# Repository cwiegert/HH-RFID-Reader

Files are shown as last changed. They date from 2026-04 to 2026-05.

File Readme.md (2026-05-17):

# EMU NFC Gate Reader

> NFC spool identification for Happy Hare: use one reader per EMU lane, or one shared reader inside the MMU body.

This project supports two operating models:

- **Per-lane readers:** each EMU gate gets its own PN532 reader. When you load a spool, NFC can scan-jog the filament until the tag rotates into read range, resolve the spool in Spoolman, and update Happy Hare's gate map automatically.
- **Shared reader:** one PN532 is mounted inside the MMU body. Tap the spool tag before loading, then insert filament into any gate. When Happy Hare starts pregate preload, NFC stages that spool ID for the gate being loaded.

Per-lane flow:

```
Load spool → HH parks filament → scan-jog rotates spool → tag in range → Spoolman lookup → Happy Hare gate map
```

Shared-reader flow:

```
Tap tag → spool pending → load any MMU gate → HH pregate preload → spool assigned
```

---

## What You Need

- A Voron with an EMU running ~~[Happy Hare](https://github.com/moggieuk/Happy-Hare)~~
- The [igiannakas IG-dev branch](https://github.com/igiannakas/Happy-Hare/tree/IG-dev) of Happy Hare.
- One mcu per filament lane (EBB36, EBB42, or SLB)
- One PN532 NFC reader module per gate (~$3–5 each)    the holder is designed for [35mm PCB](https://www.amazon.com/dp/B0DDKX2JCD)
- M2 x 4 self-tapping screws to mount each PN532 to the bracket
- Spoolman running and accessible from the Pi
- NFC tags on your spools (NTAG213/215/216 or Mifare Classic)

---

## Documentation

| | Guide | What it covers |
|---|---|---|
| 1 | [Wiring](docs/i2c-pn532/wiring.md) | Pin connections, I2C mode selection, pull-ups |
| 2 | [Install](docs/shared/install-uninstall.md) | Clone, run installer, configure Moonraker updates |
| 3 | [Setup](docs/i2c-pn532/setup.md) | printer.cfg includes, lane config, first boot |
| 4 | [Spoolman Integration](docs/shared/spoolman-integration.md) | Create the extra field, register tag UIDs |
| 5 | [Commands & Macros](docs/shared/klipper-functions.md) | Every GCode command with examples |
| 6 | [Configuration Reference](docs/shared/configuration.md) | All settings with defaults |
| 7 | [Message Definitions](docs/shared/message_definition.md) | Console messages and `nfc_reader.log` entries for per-lane and shared readers |
| 8 | [Troubleshooting](docs/i2c-pn532/troubleshooting.md) | Failure patterns and fixes |
| 9 | [How It Works](docs/shared/how-it-works.md) | Boot sequence, poll flow, system layers, macro events |
| 10 | [Expert: Low-Level I2C Debug](docs/shared/expert-low-level-i2c-debugging.md) | Manual PN532 bus commands |

---

## Scan-and-Jog: How the Tag Gets Read

NFC tags sit on the spool hub. When Happy Hare parks filament at the gate the hub face may not be aligned over the antenna — the tag could be facing any direction. Scan-and-jog solves this automatically.

**Automatic path (normal operation):**
1. Happy Hare finishes loading filament and sets gate_status → 1 (parked)
2. NFC_Manager detects the 0→1 edge on the next poll tick
3. The scan-jog loop starts — filament advances in `scan_jog_mm` steps (default 75 mm), reading the NFC tag after each step
4. The moment the tag rotates into read range, the spool is identified through Spoolman and dispatched to Happy Hare
5. The filament rewinds to the parked position via `MMU_UNLOAD restore=0`

**Manual trigger:** If the automatic trigger didn't fire (or you want to retry), run:
```gcode
NFC GATE=0 JOG_SCAN=1
```
This runs the exact same sequence with the same precondition checks (HH idle, not printing, no other gate scanning).

**Happy Hare post-preload hook (alternative to automatic polling):** The [igiannakas IG-dev branch](https://github.com/igiannakas/Happy-Hare/tree/IG-dev) of Happy Hare adds a `variable_user_post_preload_extension` hook. Configure it to trigger NFC scan-jog automatically after each `MMU_PRELOAD`:

```ini
[gcode_macro _MMU_SEQUENCE_VARS]
variable_user_post_preload_extension: 'NFC JOG_SCAN=1'
```

Happy Hare appends `GATE=<n>` automatically, giving `NFC JOG_SCAN=1 GATE=<n>`. Use this recommended config with the hook:

```ini
startup_polling: 0
scan_enabled:    False
```

This disables gate-status polling entirely — Happy Hare calls NFC only after the relevant gate completes preload. See [Configuration Reference](docs/shared/configuration.md) for full details.

**Tag-not-in-Spoolman behavior:** If the tag UID is detected but not registered in Spoolman, the gate is kept `AVAILABLE=1` with `SPOOLID=-1` so Happy Hare still treats the lane as loaded. The console prompts the user to add the UID to Spoolman.

**Configurable per lane** — see [Configuration Reference](docs/shared/configuration.md):

| Key | Default | Effect |
|---|---|---|
| `scan_enabled` | `False` | Automatic gate-status trigger; keep `False` when using the Happy Hare post-preload hook |
| `scan_jog_mm` | `75.0` | Filament advance per step (mm) |
| `scan_reads_per_position` | `3` | NFC read attempts at each stopped scan position before the next substep |
| `scan_rewind_buffer_mm` | `30.0` | Distance left for Happy Hare's final gate parking step |
| `scan_decode_retry_mm` | `2.0` | Distance between nearby retry positions after an incomplete rich tag read |
| `scan_decode_retry_rounds` | `5` | Nearby retry rounds; each round probes both sides of the first UID hit |
| `scan_poll_interval` | `0.1` | Seconds between stopped-position NFC reads during scan |

During scan-jog, gate `N` also guards against the rare case where its reader
sees the parked spool on gate `N - 1`. If the read UID exactly matches the left
neighbor's cached UID, NFC shifts that neighbor 75 mm out of range, continues
scanning the current gate, and restores the neighbor on scan exit.

---

## Shared Reader

An optional single PN532 mounted inside the MMU body — not tied to any EMU lane. Tap a tagged spool on it before loading; Happy Hare automatically assigns that spool to whichever gate gets the next pregate preload.

```
tap spool on shared reader → blinking LED → spool pending
insert filament into MMU gate → pregate preload → HH assigns spool ID
```

Happy Hare already has the mechanism:

```gcode
MMU_GATE_MAP NEXT_SPOOLID=<spool_id>
```

The shared reader issues this command at `variable_user_pre_load_extension` time — just before preload starts. Happy Hare assigns it to the loaded gate; NFC clears the pending state.

**Setup:** include `nfc_reader_shared.cfg` and wire the Happy Hare pre-load hook to `_NFC_SHARED_PRELOAD`. See [Shared Reader](docs/shared/shared-reader.md) for the full workflow, [Configuration Reference](docs/shared/configuration.md#shared-reader) for the config block, and [Commands & Macros](docs/shared/klipper-functions.md#shared-reader) for operation.

---

## Quick Install

> [!IMPORTANT]
> Before installing, rebuild and flash Klipper firmware on every EBB42 / lane MCU. The NFC driver talks to the MCU directly over I2C — if MCU firmware is stale, failures look like hardware problems. See [the full warning below](#mcu-firmware-warning).

SSH to the Pi and clone the repo:

```bash
cd ~
git clone https://github.com/cwiegert/HH-RFID-Reader.git emu-nfc-reader
cd ~/emu-nfc-reader
bash install.sh
```

Add the matching includes to `printer.cfg` — **order matters**.

Per-lane readers:

```ini
[include nfc/nfc_reader.cfg]
[include nfc/nfc_macros.cfg]
[include nfc/nfc_reader_hw.cfg]
```

Shared-reader-only:

```ini
[include nfc/nfc_reader.cfg]
[include nfc/nfc_macros.cfg]
[include nfc/nfc_reader_shared.cfg]
```

Hybrid install with per-lane readers and a shared reader:

```ini
[include nfc/nfc_reader.cfg]
[include nfc/nfc_macros.cfg]
[include nfc/nfc_reader_hw.cfg]
[include nfc/nfc_reader_shared.cfg]
```

Set your Spoolman URL in `~/printer_data/config/nfc/nfc_reader.cfg`:

```ini
[nfc_gate]
spoolman_url:      auto
spoolman_rfid_key: rfid_tag
```

Add the Moonraker update block to `moonraker.conf`:

```ini
[update_manager emu_nfc_reader]
type:             git_repo
path:             ~/emu-nfc-reader
origin:           https://github.com/cwiegert/HH-RFID-Reader.git
primary_branch:   main
managed_services: klipper
install_script:   install.sh
info_tags:        desc=EMU NFC Gate Reader for Happy Hare
```

Restart and verify:

```bash
sudo systemctl restart klipper moonraker
```

```gcode
NFC_STATUS
```

Expected (with no tags loaded):
```
NFC gate status  (4 gates configured):
  Gate 0  [lane0]:  empty
  Gate 1  [lane1]:  empty
  Gate 2  [lane2]:  empty
  Gate 3  [lane3]:  empty
```

See [Install & Uninstall](docs/shared/install-uninstall.md) for the complete first-boot checklist.

---

## Day-to-Day Commands

These are the commands you'll actually use at the Fluidd/Mainsail console:

```gcode
NFC_HELP                      ; show everyday command help
NFC_HELP ADVANCED=1 CALLBACKS=1 LOW_LEVEL=1  ; show the full command set
NFC_STATUS                    ; see all gates at a glance
NFC GATE=0 SCAN=1             ; read a tag and show its UID
NFC GATE=0 POLL=1             ; full cycle: read → Spoolman → Happy Hare
NFC GATE=0 JOG_SCAN=1         ; start scan-jog (same as automatic pre-load trigger)
NFC GATE=0 READ=1             ; start automatic background polling
NFC GATE=0 READ=0             ; stop polling
```

See [Commands & Macros](docs/shared/klipper-functions.md) for everything, including how to test the Happy Hare handoff without hardware.

---

See [How It Works](docs/shared/how-it-works.md) for the boot sequence, per-poll flow, system layers, and macro dispatch events.

---

> [!CAUTION]
> ## 🔴⚡ Your Lane MCUs Should Run Firmware Built From Your Current Host firmware version
>
> This is the number one cause of mysterious NFC failures — and it looks nothing like a firmware problem. It looks like broken wiring, a dead PN532, a misconfigured I2C bus, or a ghost in the machine.
>
> **Here's what's actually happening:** The PN532 driver doesn't talk to Klipper software on the Pi. It talks directly to the firmware running on each EBB42 over I2C. When you run `git pull` on the Pi, the host updates — but every lane MCU is still running whatever firmware it had before. Now they speak different protocol versions, and I2C transactions start silently failing:
>
> - 🔇 ACK reads fail immediately after the ready byte succeeds
> - ⏱️ `i2c_read_response` timeouts appear out of nowhere
> - 🌡️ Your BME280 on the same bus starts misbehaving for no apparent reason
>
> **The fix is not in the wiring. It is not in the config. It is in the firmware.**
>
> Every time you update Klipper — before you touch NFC config, before you run `INIT`, before you blame the hardware — do this:
>
> ```
> 1. git pull                          ← update the Klipper host checkout
> 2. Build MCU firmware                ← compiled from THAT exact host version
> 3. Flash every lane MCU / EBB42      ← every one, not just lane0
> 4. sudo systemctl restart klipper
> 5. Confirm all lane MCUs reconnect   ← check Fluidd/Mainsail before testing NFC
> ```
>
> ✅ Host and MCU firmware versions match → NFC works reliably
> ❌ Host updated, MCUs not reflashed → NFC fails in ways that will waste hours

---

## License

Copyright (C) 2026 WoodWorker.
Licensed under [GNU General Public License v3.0 or later](https://www.gnu.org/licenses/gpl-3.0.html).
See [LICENSE](LICENSE) for the full terms.

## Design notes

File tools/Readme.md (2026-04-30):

# pn532_scan.py — Standalone PN532 Scanner

Reads a PN532 NFC reader directly from a Raspberry Pi using the native Linux
I2C layer — no Klipper, no MCU, no CAN bus required.

Use this to confirm wiring and tag detection before integrating with Klipper.

---

## Prerequisites

### Enable I2C on the Pi

```bash
sudo raspi-config
```

Navigate to **Interface Options → I2C → Enable**, then reboot.

Confirm the device is present:

```bash
ls /dev/i2c-*
# expected: /dev/i2c-1
```

### Install smbus2

```bash
sudo apt install python3-smbus2
```

---

## Wiring

| PN532 Pin | Pi Pin | Pi GPIO |
|---|---|---|
| VCC | Pin 1 | 3.3V |
| GND | Pin 6 | GND |
| SDA | Pin 3 | GPIO2 (I2C1 SDA) |
| SCL | Pin 5 | GPIO3 (I2C1 SCL) |

> **I2C mode:** Set the PN532 to I2C mode before wiring (DIP switch or solder jumper).
>
> | SEL0 | SEL1 | Mode |
> |---|---|---|
> | L | L | SPI |
> | **H** | **L** | **I2C ← use this** |
> | L | H | HSU (UART) |

> **Default address:** `0x24` — change with `--address` if your ADDR pins are set differently.

---

## Usage

Run from the repository root on the Pi.

### Step 1 — Confirm the PN532 is visible on the bus

```bash
python3 tools/pn532_scan.py --scan-bus
```

Expected output:

```
Scanning I2C bus 1 for devices...
  0x24  (36)

1 device(s) found.
```

If nothing appears — check wiring and the I2C mode jumper.

---

### Step 2 — Poll for tags

```bash
python3 tools/pn532_scan.py
```

```
PN532 scanner — I2C bus 1, address 0x24
Poll interval: 2.0s   Debug: 1
Press Ctrl+C to stop.

Initialising PN532...
PN532 ready.

TAG DETECTED  UID=A3F200CC
Tag removed.
```

Press **Ctrl+C** to stop.

---

### Options

| Option | Default | Description |
|---|---|---|
| `--bus N` | `1` | I2C bus number (`/dev/i2c-N`) |
| `--address 0xNN` | `0x24` | PN532 I2C address |
| `--poll N` | `2.0` | Poll interval in seconds |
| `--debug` | off | Full protocol trace (every I2C transaction) |
| `--once` | off | Exit after first tag read |
| `--scan-bus` | off | Scan bus for all responding devices and exit |

---

### Full protocol trace

```bash
python3 tools/pn532_scan.py --debug
```

Prints every I2C transaction — useful when the PN532 initialises but tags are not detected.

---

### Read one tag and exit

```bash
python3 tools/pn532_scan.py --once
```

---

## Troubleshooting

**"smbus2 is not installed"**
```bash
sudo apt install python3-smbus2
```

**"ERROR: PN532 gate 0 did not respond"**
1. Run `--scan-bus` — if `0x24` is not listed the chip is not on the bus
2. Confirm the PN532 is in **I2C mode** — most common cause of no response
3. Check VCC is **3.3V** (not 5V), SDA → Pin 3, SCL → Pin 5
4. Confirm I2C is enabled: `sudo raspi-config → Interface Options → I2C`

**"Permission denied: /dev/i2c-1"**
```bash
sudo usermod -aG i2c $USER
# log out and back in, then retry
```

**Tag not detected**
- Hold tag flat and close (< 3 cm) to the antenna coil
- Run `--debug` to see whether `InListPassiveTarget` is completing
- Try rotating the tag — some tags are orientation-sensitive

---

*Copyright (C) 2026 WoodWorker. Licensed under [GPL-3.0-or-later](https://www.gnu.org/licenses/gpl-3.0.html) — see [LICENSE](../LICENSE).*

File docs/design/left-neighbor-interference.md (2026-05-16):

# Design: Left-Neighbor Tag Interference During Scan-Jog

> Engineering reference. Not end-user documentation.
> Status: **Implemented** — `scan_jog.py` mitigation, `nfc_manager.py`
> lane lookup support, and scan-jog tests.

## Problem

Some tagged spools expose NFC/RFID tags on both sides of the spool. In an EMU
layout where each PN532 reader is mounted on the left side of its own spool, the
reader for gate `N` can occasionally see the tag on gate `N - 1` instead of the
spool currently being scan-jogged.

This is most likely during scan-jog:

- gate `N` is rotating to find its own tag
- gate `N - 1` is already loaded and parked
- one side tag on gate `N - 1` is sitting in gate `N` reader's field

The current NFC state machine assumes the UID returned by a gate reader belongs
to that gate. That assumption is still correct for normal operation, but it can
misassign a spool during this physical edge case.

## Scope

Recommended scope is intentionally narrow:

- only inspect the immediate left neighbor, `gate - 1`
- do nothing for gate `0`
- only apply mitigation while scan-jog is active
- only apply mitigation while Happy Hare is idle and lanes passed the existing
  parked-or-empty preflight
- do not add a configuration option
- always restore the left neighbor if it was moved
- do not add global cross-gate UID matching

This keeps the behavior matched to the physical mounting geometry instead of
turning the NFC manager into a global spool reconciliation system.

## Existing Safety Boundaries

The current implementation already provides useful protection:

- only one scan-jog may run at a time via `NFCGate._active_scan_gate`
- scan-jog is blocked unless Happy Hare reports all lanes parked or empty
- each gate owns its own reader
- scan-jog suppresses dispatch until after the rewind path
- incomplete structured reads can be retried nearby

The missing piece is identity disambiguation after a UID is read but before the
scan is accepted as successful.

## Insertion Point

The implementation lives in:

`klippy/extras/nfc_gates/scan_jog.py`

The best insertion point is inside `step_event()`, immediately after:

```python
tag_found = gate._poll()
```

and before the existing `if tag_found:` success path.

At this point:

- the PN532 read has happened
- `tag_handler.resolve_spool()` has already resolved UID to spool where possible
- `GateState.process_read()` has updated `gate._state`
- scan-jog dispatch is still deferred in `gate._scan_found_event`
- no Happy Hare assignment has been sent yet

That makes it possible to reject the read, clear the deferred event, move the
left neighbor out of the RF field, and continue scanning gate `N`.

Implemented call shape:

```python
tag_found = gate._poll()

if tag_found and handle_left_neighbor_interference(gate, now):
    return gate.reactor.monotonic() + gate._scan_poll_interval
```

## Detection Strategy

### Spoolman-enabled path

If Spoolman is enabled, the first identity test should still be UID-to-UID, not
UID-to-spool. The raw UID is the direct physical identity returned by the PN532.
If gate `N` reads the same UID already known for gate `N - 1`, the tag belongs
to the left neighbor and there is no reason to resolve the read UID to a
Spoolman spool before acting.

Implemented order:

1. Confirm gate `N` parsed a `spool_identity`.
2. Find the known `spool_identity` for gate `N - 1` from the left NFC gate
   object's `current_tag`.
3. If the left gate has a known `spool_identity` and it matches the current
   identity, treat the read as interference immediately.
4. Discard the read, jog gate `N - 1` out of the reader field, and continue
   scan-jog for gate `N`.
5. If either identity is unavailable or they do not match, fall out to the
   default scan-jog behavior.

This avoids unnecessary Spoolman resolution for the strong-match case. The
identity comparison answers "did this reader see the same factory spool as the
left gate?" without relying on physical tag UIDs.

Helper logic:

```python
def read_uid_from_scan_event(gate):
    event = getattr(gate, '_scan_found_event', None)
    if event is not None and len(event) >= 3:
        return event[2]
    return gate._state.current_uid
```

Then:

```python
left_gate = gate._gate - 1
if left_gate < 0:
    return False

current_identity = current_spool_identity(gate)
if current_identity is None:
    return False

left_identity = spool_identity_for_gate(gate, left_gate)
if left_identity is not None and left_identity == current_identity:
    return True
```

The `spool_identity_for_gate()` helper is cheap and conservative. Preferred source:

1. The left `NFCGate.current_tag.spool_identity`, if present.

Happy Hare may be used as a safety check that the left gate is still physically
loaded or available, but it should not be used to resolve identity. Likewise,
the implementation must not fall back from `spool_identity` to `uid`,
`spool_id`, material, color, or display metadata. If either side has no
`spool_identity`, there is no positive interference proof.

If no left `spool_identity` can be established, or if the known left identity
does not match the current identity, the mitigation should return `False` and
let normal scan-jog continue. The resolved `spool_id` is useful for the normal
assignment flow, but it is not the decision point for left-neighbor
interference.

### Spoolman-disabled path

When Spoolman is disabled, the same `spool_identity` rule still applies. Do not
invent a Happy Hare metadata convention just to smuggle identity through display
names. The NFC layer already owns per-gate state, and `NFC_STATUS` shows each
gate's cached `spool_identity` when parser metadata supplies one.

Recommended order:

1. Confirm gate `N` has `current_tag.spool_identity`.
2. Resolve the left NFC gate object for `N - 1`.
3. Read `left_gate._state.current_tag.spool_identity`.
4. If the left NFC gate has a cached `spool_identity` and it matches the
   current identity, treat the read as interference immediately.
5. If either side has no `spool_identity`, or the identities do not match,
   return `False` and let normal scan-jog continue.

This keeps the no-Spoolman path a corner case with the same core rule:

```python
left_nfc = nfc_gate_for_gate_number(gate._gate - 1)
if left_nfc is None:
    return False

left_identity = left_nfc._state.current_tag.spool_identity
return left_identity is not None and left_identity == current_identity
```

Happy Hare can still be used as a sanity check that the left lane is physically
loaded or available, but HH does not need to carry the identity. Identity
comparison comes from NFC parser metadata, not from gate names or display
metadata.

## Mitigation Strategy

If the current scan reads the left neighbor:

1. Log the decision, including current gate, left gate, UID, and spool ID when
   available.
2. Select the left gate.
3. Jog the left gate in the positive `MMU_TEST_MOVE` direction by a fixed
   distance. This is the "push filament out" direction for the parked left
   neighbor.
4. Wait for the move to complete.
5. Re-select the current scan gate.
6. Clear the false scan result.
7. Continue the scan-jog loop.

Up to three clearance moves may be attempted per scan. After each move, the
false scan result is cleared and the current lane reads again before any normal
current-lane jog is queued. If the same scan still reads the left neighbor
after the third clearance move, treat that as a larger mechanical/RF fault.
Log and console an `[ERROR]`, abort scan-jog for the current gate, restore the
left neighbor by the accumulated clearance distance, and rewind the current
gate through the normal scan exit path.

Fixed distance:

```python
LEFT_NEIGHBOR_CLEARANCE_MM = 75.0
```

No config option is recommended. A fixed value keeps the feature simple and
avoids adding a tuning knob for a rare hardware geometry problem.

Clearance GCode sequence:

```gcode
MMU_SELECT GATE=<left>
MMU_TEST_MOVE MOVE=75.00 QUIET=1
M400
MMU_SELECT GATE=<current>
```

After shifting the neighbor, clear the false read:

```python
gate._scan_found_event = None
gate._state.current_uid = None
gate._state.current_spool = None
gate._state.miss_count = 0
```

If a structured tag object is present, clear it as well:

```python
gate._state.current_tag = None
```

## Restore Strategy

If the left neighbor was moved, it must be restored from every scan exit path:

- successful scan
- no tag found
- max distance reached
- print-start abort
- scan poll exception path that exits scan-jog

State on `NFCGate`:

```python
gate._scan_left_neighbor_gate = -1
gate._scan_left_neighbor_shift_mm = 0.0
gate._scan_left_neighbor_shifted = False
gate._scan_left_neighbor_identity = None
gate._scan_left_neighbor_attempts = 0
```

Initialize these in `scan_jog.start()`.

Restore helper:

```python
def restore_left_neighbor(gate):
    if not getattr(gate, '_scan_left_neighbor_shifted', False):
        return
    left = gate._scan_left_neighbor_gate
    mm = gate._scan_left_neighbor_shift_mm
    gate._scan_left_neighbor_shifted = False
    gate._scan_left_neighbor_gate = -1
    gate._scan_left_neighbor_shift_mm = 0.0
    gate._scan_left_neighbor_identity = None

    gcode = gate.printer.lookup_object('gcode')
    gcode.run_script(
        "MMU_SELECT GATE=%d\n"
        "MMU_TEST_MOVE MOVE=%.2f QUIET=1\n"
        "M400\n"
        "MMU_SELECT GATE=%d" % (left, -mm, gate._gate))
```

Call this from both `finish()` and `rewind_and_exit()`. The restore should run
after the current gate's rewind is queued, and before the scan state is fully
cleared. The final `MMU_SELECT GATE=<current>` leaves Happy Hare selected on the
gate whose scan just completed.

## State Reset and Scan Continuation

Handling interference should not count as a successful scan. It should behave
like "that UID was not ours; try again after moving the neighbor".

Recommended behavior after the left gate jog:

- keep `gate._scan_mode = True`
- keep `NFCGate._active_scan_gate` held by the current gate
- keep `gate._scan_mm_total` unchanged
- clear current NFC state and deferred event
- set `gate._scan_next_chunk_time` to a short future time so the field can
  settle before polling again

Example:

```python
gate._scan_next_chunk_time = (
    gate.reactor.monotonic() + DECODE_RETRY_SETTLE_DELAY)
```

Using the existing decode retry settle constant is acceptable. A separate
constant can be introduced if hardware testing shows the neighbor shift needs a
different dwell.

## Implementation Notes

This section describes the implemented first pass.

### Identity Rule

Use exactly one positive interference rule:

```text
gate N current_tag.spool_identity = X
left NFC gate current_tag.spool_identity = Y
X exists and Y exists and X == Y -> left-neighbor interference
X missing or Y missing          -> normal scan-jog behavior
X != Y                          -> normal scan-jog behavior
```

This is deliberately conservative for dual-tag factory spools where the two
physical tags have different UIDs. Bambu spools are one observed case: both side
tags can parse to the same `spool_identity` (`bambu_<tray_uid>`) while exposing
different physical NFC UIDs.

Do not use physical tag UID as a fallback for this decision. Do not resolve the
read UID to a Spoolman spool ID for interference detection. Do not compare the
read spool ID to Happy Hare's left-gate spool ID. Do not inspect Happy Hare
display names, material, color, or other metadata for identity information.

### Data Sources

The current identity comes from the current gate's parsed tag state:

1. `gate._state.current_tag.spool_identity`

The left identity comes from the left NFC gate object only:

```python
left_nfc = nfc_gate_for_gate_number(gate._gate - 1)
left_identity = (
    left_nfc._state.current_tag.spool_identity
    if left_nfc is not None and left_nfc._state.current_tag is not None
    else None)
```

Happy Hare may be consulted only to reject stale left-cache data:

```python
left_hh = hh_status.read(gate.printer, gate._gate - 1)
if left_hh.present and not left_hh.available:
    return None
```

If Happy Hare is unavailable, the implementation may still use the left NFC
cache because scan-jog already passed its preflight before starting. The
important part is that HH is not used to translate the current read into an
identity.

### Helper Contracts

Add a lookup helper near the existing `_lane_instances` registry in
`nfc_manager.py`:

```python
def nfc_gate_for_gate_number(gate_number):
    for candidate in _lane_instances:
        if candidate._gate == gate_number:
            return candidate
    return None
```

Expose it to `scan_jog.py` through an `NFCGate` wrapper to avoid importing
`nfc_manager.py` from `scan_jog.py`:

```python
def _nfc_gate_for_gate_number(self, gate_number):
    return nfc_gate_for_gate_number(gate_number)
```

Then `scan_jog.py` can call:

```python
left_nfc = gate._nfc_gate_for_gate_number(gate._gate - 1)
```

### Scan Loop Placement

In `scan_jog.step_event()`, call the interference handler immediately after
`gate._poll()` and before decode retry or finish handling:

```python
tag_found = gate._poll()

if tag_found and handle_left_neighbor_interference(gate, now):
    return gate.reactor.monotonic() + gate._scan_poll_interval
```

This placement matters. `_poll()` has already captured the UID and deferred the
event, but scan-jog has not accepted the read, started decode retry, dispatched
to Happy Hare, or finished.

### Interference Handler

The handler should:

1. Read the current scan UID for logging and the current `spool_identity` for
   identity matching.
2. Return `False` for gate `0`.
3. Return `False` if the current `spool_identity` is empty.
4. Read the left NFC gate object and its cached `spool_identity`.
5. Return `False` if the left identity is empty or does not match.
6. If the left neighbor was already shifted during this scan and the same left
   gate/identity is still being read, log a fault, abort scan-jog, and return `True`.
7. Log the interference decision.
8. Move the left gate out of range. If the shift command fails, log the
   failure, clear no scan state, return `False`, and let normal scan-jog
   behavior continue.
9. Clear the current gate's false read state.
10. Keep scan-jog active and return `True`.

The handler should not inspect or compare spool IDs.

### Left-Gate Movement

Use a single fixed displacement:

```python
LEFT_NEIGHBOR_CLEARANCE_MM = 75.0
```

The shift GCode should explicitly select the left gate, move it in the positive
`MMU_TEST_MOVE` direction to push filament out, wait, then select the current
gate:

```gcode
MMU_SELECT GATE=<left>
MMU_TEST_MOVE MOVE=75.00 QUIET=1
M400
MMU_SELECT GATE=<current>
```

Set restore state only after the shift command is successfully queued:

```python
gate._scan_left_neighbor_gate = left
gate._scan_left_neighbor_shift_mm = 75.0
gate._scan_left_neighbor_shifted = True
gate._scan_left_neighbor_identity = spool_identity
```

If the shift command raises, log a warning, clear no state, and return `False`
so normal scan-jog behavior continues.

Retry clearance moves conservatively. If `gate._scan_left_neighbor_shifted` is
already `True` for the same left gate and `spool_identity`, the implementation
may call `MMU_TEST_MOVE MOVE=75.00` again until three total clearance moves
have been queued. Each retry clears the false scan result and reads again
before normal current-lane scan-jog movement resumes.

If the same `spool_identity` is still visible after the third clearance move
and follow-up read, report an error and exit scan-jog:

```text
[ERROR] NFC[<current>]: left lane gate <left> is interfering with the current lane read after 3 clearance moves (<mm>mm); check reader position, tag placement, or lane spacing
```

That exit should use the normal rewind/restore path so the neighbor is returned
with `MMU_TEST_MOVE MOVE=-<total clearance>` and the current gate is rewound.

### False Read Cleanup

After a confirmed left-neighbor `spool_identity` match and successful left-gate
shift, clear:

```python
gate._scan_found_event = None
gate._state.current_uid = None
gate._state.current_spool = None
gate._state.current_tag = None
gate._state.miss_count = 0
```

Also clear decode-retry state if it had been initialized from the false UID:

```python
gate._scan_decode_retry_attempts = 0
gate._scan_decode_retry_uid = None
gate._scan_decode_retry_offset = 0.0
```

Do not change `gate._scan_mm_total`; the current gate has not moved.

### Restore Ordering

Call `restore_left_neighbor(gate)` from both scan exit paths:

- `finish(gate)`
- `rewind_and_exit(gate)`

The restore should run after the current gate's rewind is queued and before the
scan state is fully discarded. This preserves the current gate's normal rewind
behavior and still guarantees the neighbor is put back.

Restore GCode:

```gcode
MMU_SELECT GATE=<left>
MMU_TEST_MOVE MOVE=-75.00 QUIET=1
M400
MMU_SELECT GATE=<current>
```

Clear restore state before running the restore GCode so a restore failure cannot
cause repeated negative moves on later cleanup attempts. Log failures.

## Module Changes

### `scan_jog.py`

Owns:

- interference detection wrapper
- left-neighbor jog GCode
- restore-on-exit state
- clearing false scan results

Recommended additions:

- `LEFT_NEIGHBOR_CLEARANCE_MM`
- `handle_left_neighbor_interference(gate, now)`
- `is_left_neighbor_spool_identity_match(gate)`
- `spool_identity_for_gate(gate, target_gate)`
- `shift_left_neighbor(gate)`
- `restore_left_neighbor(gate)`
- `clear_false_scan_result(gate)`

### `nfc_manager.py`

Keep changes minimal.

Add scan state fields in `NFCGate.__init__` so tests and status are explicit:

```python
self._scan_left_neighbor_gate = -1
self._scan_left_neighbor_shift_mm = 0.0
self._scan_left_neighbor_shifted = False
self._scan_left_neighbor_identity = None
```

Expose or reuse a small lookup helper for the existing NFC gate registry:

```python
def nfc_gate_for_gate_number(gate_number):
    for candidate in _lane_instances:
        if candidate._gate == gate_number:
            return candidate
    return None
```

This helper lets scan-jog read the left gate's cached `current_tag` directly
from the NFC gate object. Parser-supplied `spool_identity` is the source for
this mitigation; Happy Hare does not need an identity field.

No Happy Hare movement commands should be added here. Movement remains in
`scan_jog.py`.

### `hh_status.py`

No display-name or metadata changes are required for this design.

`hh_status.py` may still be used to verify the left lane is physically loaded or
available before trusting a cached `spool_identity`, but it should not be
extended to carry identity through Happy Hare gate metadata.

### `klipper_interface.py`

No changes are required.

Do not append identity suffixes to metadata names for this mitigation. Display
names should remain display names; spool identity stays in NFC parser metadata.

## Pseudocode

```python
def handle_left_neighbor_interference(gate, now):
    if not gate._scan_mode:
        return False
    if gate._gate <= 0:
        return False

    identity = current_spool_identity(gate)
    if identity is None:
        return False

    if not is_left_neighbor_spool_identity_match(gate):
        return False

    left_gate = gate._gate - 1
    if left_neighbor_already_shifted(gate, left_gate, identity) and attempts >= 3:
        msg = (
            "[ERROR] NFC[%d]: left lane gate %d is interfering with the "
            "current lane read after %d clearance moves"
            % (gate._gate, left_gate, attempts))
        logger.error("%s", msg)
        gate._console(msg)
        clear_false_scan_result(gate)
        gate._rewind_and_exit_scan()
        return True

    logger.warning(
        "nfc_gate: [%s] gate %d scan mode - spool_identity=%s belongs "
        "to left neighbor gate %d; moving neighbor out of reader field",
        gate._name, gate._gate, identity, left_gate)

    if not shift_left_neighbor(gate):
        return False
    clear_false_scan_result(gate)
    gate._scan_next_chunk_time = (
        gate.reactor.monotonic() + DECODE_RETRY_SETTLE_DELAY)
    return True

def left_neighbor_already_shifted(gate, left_gate, identity):
    return (
        gate._scan_left_neighbor_shifted
        and gate._scan_left_neighbor_gate == left_gate
        and gate._scan_left_neighbor_identity == identity)

def current_spool_identity(gate):
    tag = gate._state.current_tag
    return getattr(tag, 'spool_identity', None) if tag is not None else None

def is_left_neighbor_spool_identity_match(gate):
    if gate._gate <= 0:
        return False
    identity = current_spool_identity(gate)
    if identity is None:
        return False

    left_gate = gate._gate - 1
    left_identity = spool_identity_for_gate(gate, left_gate)
    if left_identity is None:
        return False

    return left_identity == identity

def spool_identity_for_gate(gate, target_gate):
    left_nfc = gate._nfc_gate_for_gate_number(target_gate)
    left_tag = left_nfc._state.current_tag if left_nfc is not None else None
    left_identity = (
        getattr(left_tag, 'spool_identity', None)
        if left_tag is not None else None)
    if left_identity is None:
        return None

    # Optional stale-cache guard. HH is not used to resolve identity; it can
    # only veto cached left metadata when it clearly says the left gate is empty.
    left = hh_status.read(gate.printer, target_gate)
    if left.present and not left.available:
        return None

    return left_identity
```

## Tests

Add tests to:

`tests/test_scan_jog_mode.py`

Recommended cases:

- gate `0` never checks a left neighbor
- read matching the known left `spool_identity` shifts left and does not finish
  scan
- read with a different left `spool_identity` finishes normally
- read with no known left `spool_identity` falls through to normal scan-jog
  behavior
- left gate assigned but not available does not trigger mitigation
- after interference, false `_scan_found_event` and `GateState` values are
  cleared
- `finish()` restores the left gate if shifted
- `rewind_and_exit()` restores the left gate if shifted
- repeated left-neighbor hits after the first clearance do not issue another
  `MOVE=75.00`; they warn, abort scan-jog, restore the neighbor, and rewind the
  current gate
- Spoolman-disabled reads use the same parser-supplied `spool_identity` rule

The tests should assert emitted GCode order, especially:

```text
MMU_SELECT GATE=<left>
MMU_TEST_MOVE MOVE=75.00 QUIET=1
M400
MMU_SELECT GATE=<current>
```

and restore:

```text
MMU_SELECT GATE=<left>
MMU_TEST_MOVE MOVE=-75.00 QUIET=1
M400
MMU_SELECT GATE=<current>
```

## Risks and Notes

- The no-Spoolman path depends on parser metadata having supplied
  `spool_identity` for both the current and left NFC gate objects. If either is
  missing, the mitigation should degrade gracefully by returning `False` and
  letting normal scan-jog continue.
- Moving the left neighbor assumes all lanes are parked or empty. The existing
  scan-jog preflight is therefore part of this feature's safety case.
- If the reader still sees the same left-neighbor `spool_identity` after a 75mm
  clearance move, the problem is likely mechanical placement, reader field
  overlap, tag placement, or lane spacing. The implementation should surface
  that condition clearly and stop the scan instead of pushing the neighbor
  farther out.
- The mitigation should be conservative about what counts as interference.
  False positives move a neighboring parked spool unnecessarily. False
  negatives preserve current behavior.
- The feature should log clearly but avoid console spam. A single warning per
  interference event is enough.

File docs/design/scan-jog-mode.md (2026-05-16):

# Design: Scan-and-Jog Mode (Spool Pre-load NFC Identification)

> Engineering reference — not end-user documentation.
> Status: **Implemented** — `scan_jog.py` module, integrated into `nfc_manager.py`
> Source: `klippy/extras/nfc_gates/scan_jog.py`, `klippy/extras/nfc_gates/nfc_manager.py`

---

## Problem Statement

When a spool is manually loaded into a lane, Happy Hare parks the filament at the gate entrance (gate_status → 1, action → Idle). At that point the NFC tag is on the spool hub — potentially centimeters away from the PN532 antenna. The normal polling loop may not read the tag at all if the hub face isn't already aligned over the reader. The user needs a mode where, after filament is parked at the gate, the system automatically spins the spool in small increments to find the tag, identifies the spool, and then winds back to the parked position.

---

## Constraints

- Must not run during an active print.
- Must not run while HH is executing any MMU operation (Loading, Unloading, Homing, etc.).
- Must not require a GCode macro to drive the loop — the control logic must stay in Python.
- Must rewind to the original parked position.
- Rewind must fire even if the search is aborted (max distance reached, print starts mid-scan).
- Must not use `UPDATE_DELAYED_GCODE` — timer lifecycle is owned entirely by the Klipper reactor.

---

## Why Not a GCode Macro Loop

Driving the jog loop from GCode would require a `[delayed_gcode]` that reschedules itself, a cancel mechanism (no clean cancel exists), and scope crossing on every iteration. The Python-only approach eliminates all three problems. Reactor timers are first-class objects: they start, reschedule, and cancel entirely within `_scan_step_event` return values. The jog command (`MMU_TEST_MOVE`) is still issued via `gcode.run_script()`, which is safe from the reactor thread — the same pattern used by `KlipperInterface._run_gcode()`.

---

## Code Structure

All scan-jog logic lives in `klippy/extras/nfc_gates/scan_jog.py` as module-level functions. `NFCGate` in `nfc_manager.py` delegates to them via thin wrapper methods:

```python
# NFCGate wrappers in nfc_manager.py
def _start_scan_mode(self):   return scan_jog.start(self)
def _scan_step_event(self, t): return scan_jog.step_event(self, t)
def _finish_scan(self):        return scan_jog.finish(self)
def _rewind_and_exit_scan(self): return scan_jog.rewind_and_exit(self)
def _run_jog(self, mm):        return scan_jog.run_jog(self, mm)
def _run_rewind(self):         return scan_jog.run_rewind(self)
```

`gate` is passed as the first argument to every `scan_jog` function so it can read and write `gate._scan_mode`, `gate._scan_mm_total`, etc. directly.

---

## Trigger Detection

Trigger detection is folded into `_poll_timer_event`. The gate-status edge-detection path runs every tick when `scan_enabled` is True:

```
_poll_timer_event (every poll_interval)
  ├── read HH gate_status (Python dict — no I2C)
  │
  ├── curr == 0  → skip I2C entirely; also handles _hh_load_paused resume/suspend
  │
  ├── 0→1 edge  → set _scan_pending = True; reset _scan_idle_ready_time
  │
  ├── _scan_pending == True AND curr == 1 AND hh.idle AND not printing
  │     first fire:  _scan_idle_ready_time = now + 2.0  → return that time
  │     settled:     _scan_pending = False
  │                  if NFCGate._active_scan_gate is not None:
  │                      re-arm _scan_pending, retry in 3.0 s
  │                  else:
  │                      _start_scan_mode() → park poll timer, return NEVER
  │
  └── _scan_pending == True but conditions not met → return now + 1.0
```

**Key details:**
- `_prev_gate_status` initializes to `-1` on startup. The `-1 → 1` transition at cold start is ignored; only `0 → 1` triggers scan mode. This prevents a false trigger when HH already has `gate_status = 1` from a previous session.
- A 2-second idle-settle delay (`_scan_idle_ready_time`) is inserted after HH reports idle. This prevents premature scan entry while HH is still completing its park move.
- If another gate holds the scan lock, `_scan_pending` is re-armed and a 3-second retry is scheduled rather than silently dropping the trigger or spamming logs.

**Manual trigger:** `NFC GATE=N JOG_SCAN=1` calls `scan_jog.manual_jog_scan(gate, gcmd)` directly. It runs the same precondition checks (not printing, HH idle, no other gate scanning, reader healthy) and calls `start(gate)`. No edge detection is involved. Happy Hare prep is always required, but `_NFC_GATE_CLEAR_CACHE GATE=N` and `MMU_SPOOLMAN SYNC=1` are deferred to the scan timer so a Happy Hare post-preload hook can return before NFC calls back into HH.

---

## Gate Context and Scan Lock

If two lanes entered scan mode concurrently, their `MMU_SELECT GATE=N` calls would interleave and `MMU_TEST_MOVE` would move the wrong lane's filament. Because all `nfc_gate` instances run on the same reactor thread, a **class-level lock** is sufficient:

```python
# Class variable — shared across all NFCGate instances
NFCGate._active_scan_gate = None   # gate number that currently holds the lock, or None
```

Rules:
- **Entry**: `scan_jog.start()` sets `NFCGate._active_scan_gate = gate._gate`.
- **Hold**: while scan is running, `_active_scan_gate` is non-None. Other gates re-arm `_scan_pending` and retry in 3 seconds.
- **Release**: both `finish()` and `rewind_and_exit()` set `NFCGate._active_scan_gate = None`.
- `_handle_disconnect` also clears the lock if this gate owns it.

Normal polling (I2C reads, no MMU moves) is not gated by this lock.

---

## State Machine

```
              klippy:
              connect ──► POLLING ──(0→1, HH idle, not printing)──► SCAN_JOG
                           ▲                                               │
                           │        tag found OR max_mm OR print starts   │
                           └───────────────────────────────────────────────┘
```

When scan mode starts, the poll timer is parked at `NEVER` and `_scan_timer` takes over. When scan mode ends, `_scan_timer` returns `NEVER` and the poll timer is resumed.

---

## Instance State Variables

```python
# Class variable — shared across all NFCGate instances
NFCGate._active_scan_gate = None   # gate number holding the scan lock, or None

# Timers
self._scan_timer           = None      # registered only during active scan

# Scan mode
self._scan_mode            = False
self._scan_mm_total        = 0.0       # mm jogged forward so far
self._scan_next_chunk_time = 0.0       # reactor timestamp when next jog chunk may fire
self._scan_found_event     = None      # cached event suppressed during jog; dispatched after rewind

# Left-neighbor interference mitigation
self._scan_left_neighbor_gate = -1
self._scan_left_neighbor_shift_mm = 0.0
self._scan_left_neighbor_shifted = False
self._scan_left_neighbor_identity = None
self._scan_left_neighbor_attempts = 0

# Trigger detection
self._prev_gate_status     = -1        # -1 = cold start (no 0→1 false trigger)
self._scan_pending         = False     # armed on 0→1; fires when HH confirms idle
self._scan_idle_ready_time = 0.0       # timestamp for 2s HH-idle settle delay
```

---

## Config Keys

All added to `[nfc_gate]` (overridable per `[nfc_gate laneN]`):

| Key | Python fallback | Shipped `nfc_reader.cfg` | Meaning |
|---|---|---|---|
| `scan_enabled` | `True` | `False` | Controls the automatic gate-status trigger; `JOG_SCAN` still works when false |
| `scan_jog_mm` | `50.0` | `75.0` | Logical filament advance per scan chunk (mm), divided into three stopped-position substeps |
| `scan_reads_per_position` | `3` | `3` | NFC read attempts at each stopped spool position before moving the next substep |
| `scan_decode_retry_mm` | `2.0` | `2.0` | Distance between nearby retry positions |
| `scan_decode_retry_rounds` | `5` | `5` | Nearby retry rounds before accepting the current result |
| `scan_poll_interval` | `0.1` | `0.1` | Seconds between stopped-position NFC reads during scan |

`scan_jog_mm` of 25 mm gives a ~5 cm read window (25 mm on each side of center plus the antenna width) for finding tags that are slightly off-axis.
The maximum scan distance is read at scan start from Happy Hare's
`mmu_calibration_bowden_lengths` in `mmu_vars.cfg`; the current gate indexes
that list.

---

## Implementation: `scan_jog.py`

### `start(gate, max_mm)` — enter scan mode

```python
def start(gate, max_mm=None):
    gate.__class__._active_scan_gate = gate._gate
    gate._scan_mode = True
    gate._scan_mm_total = 0.0
    gate._scan_next_chunk_time = gate.reactor.monotonic()
    gate._hh_seed_spool_id = None     # clear startup seed — scan must re-read
    gate._hh_seed_available = False
    gate._scan_found_event = None

    gate._scan_hh_prep_pending = True

    gate._scan_timer = gate.reactor.register_timer(
        gate._scan_step_event,
        gate.reactor.monotonic())
```

**`GateState.reset()`** clears `_current_uid`, `_current_spool`, `current_tag`, and `miss_count` atomically (bypassing property setters). This forces `process_read` to fire a `changed` event on the first NFC read during scan, regardless of what was previously cached. The previous uid/spool are saved to `_scan_previous_uid`/`_scan_previous_spool` before the reset for reference during the abort path.

**Pre-scan clearing sequence:**

`start()` marks HH prep pending instead of running it synchronously. The first scan timer step consumes `_scan_hh_prep_pending`, then calls `clear_hh_gate_cache` and `sync_spoolman_before_scan` before polling and before the first jog move. This keeps the required HH state updates while avoiding reentrant `gcode.run_script()` calls from inside the Happy Hare hook stack.

`clear_hh_gate_cache` issues `_NFC_GATE_CLEAR_CACHE GATE=N`. That macro calls `MMU_GATE_MAP GATE=N SPOOLID=-1 AVAILABLE=1 QUIET=1`, so Happy Hare keeps the gate loaded while clearing the stale spool assignment before scan-jog resolves the current spool. It deliberately does not write placeholder `NAME`, `MATERIAL`, or `COLOR` fields, because those can persist in Happy Hare after the real spool id is assigned.

If scan-jog cannot resolve a spool id, stale filament metadata is cleared at the unresolved exit instead of at scan start. A tag that reads but has no Spoolman match dispatches `_NFC_TAG_NO_SPOOL ... SCAN_FINISH=1`; a scan that finds no tag calls `_NFC_SCAN_UNRESOLVED GATE=N` after rewind. Both paths clear `NAME`, `MATERIAL`, `COLOR`, and `TEMP` without dumping the full Happy Hare gate map.

`sync_spoolman_before_scan` pushes the cleared HH gate state to Spoolman via `MMU_SPOOLMAN SYNC=1`, vacating the spool's location field before the jog begins.

| Trigger | `clear_hh_gate_cache` | `sync_spoolman_before_scan` |
|---|---|---|
| Automatic `0→1` poll | runs from scan timer | runs from scan timer |
| Manual `NFC JOG_SCAN=1` | runs from scan timer | runs from scan timer |
| HH post-preload hook | runs from scan timer | runs from scan timer |

When the scan succeeds, `finish()` dispatches `_NFC_SPOOL_CHANGED ... SCAN_FINISH=1` after rewind. The macro assigns the identified spool and runs `MMU_SPOOLMAN SYNC=1`. `SCAN_FINISH` remains on the event as a compatibility marker, but the default macros do not print the full Happy Hare gate map.

### `step_event(gate, eventtime)` — the loop body

```python
def step_event(gate, eventtime):
    if not gate._scan_mode:
        return gate.reactor.NEVER

    if is_printing(gate):
        gate._rewind_and_exit_scan()
        return gate.reactor.NEVER

    now = gate.reactor.monotonic()
    tag_found = gate._poll()

    if tag_found and handle_left_neighbor_interference(gate, now):
        return gate.reactor.monotonic() + gate._scan_poll_interval

    if tag_found:
        if retry_incomplete_decode(gate, now):
            return gate.reactor.monotonic() + gate._scan_poll_interval
        gate._finish_scan()
        return gate.reactor.NEVER

    if gate._scan_mm_total >= gate._scan_max_mm:
        gate._rewind_and_exit_scan()
        return gate.reactor.NEVER

    # Jog only when the previous chunk is estimated complete; poll every tick.
    if now >= gate._scan_next_chunk_time:
        remaining = gate._scan_max_mm - gate._scan_mm_total
        chunk = min(gate._scan_jog_mm, remaining)
        gate._run_jog(chunk)
        gate._scan_mm_total += chunk
        gate._scan_next_chunk_time = now + chunk_interval(gate, chunk)

    return now + gate._scan_poll_interval
```

The timer always returns `now + scan_poll_interval` so NFC is polled continuously throughout the scan. Jog chunks are gated by `_scan_next_chunk_time`, which advances by `chunk_interval = abs(mm) / gear_short_move_speed` after each issue. This decouples read frequency from motor timing — the tag can be detected anywhere in the move, not only after the chunk completes.

### `finish(gate)` — tag found

When a UID is detected but the rich payload read is marked incomplete, scan-jog queues nearby retry jogs before accepting the current UID/metadata result. The retry decision is format-neutral: reader/parser code sets `CurrentTag.read_incomplete` and `read_retry_reason`; scan-jog only applies the configured `scan_decode_retry_mm` / `scan_decode_retry_rounds` policy. Each retry round probes both sides of the first UID hit position. The first implementation marks incomplete MIFARE reads when sector authentication or block reads fail, which covers spool-mounted Bambu tags at the edge of the reader field.

### Left-neighbor interference

Some tagged spools expose a tag on both sides. With the PN532 mounted on the
left side of each lane, gate `N` can occasionally see the parked spool on gate
`N - 1` during scan-jog. The mitigation is intentionally narrow:

- only active during scan-jog
- only checks the immediate left neighbor
- only treats a read as interference when both the current read and the left
  NFC gate cache have a parser-supplied `spool_identity`, and those identities
  match
- never compares Spoolman spool IDs or Happy Hare display metadata

This deliberately ignores physical NFC tag UID for the interference decision.
Bambu AMS-style spools can carry two physical side tags with different NFC UIDs
but the same parser-supplied `spool_identity` (`bambu_<tray_uid>`). If either
side has no `spool_identity`, scan-jog treats that as no positive interference
proof and continues normally.

When the match is confirmed, scan-jog selects the left gate, moves it forward
75 mm, waits with `M400`, reselects the current gate, clears the false scan
result, and reads again. If the same left-neighbor spool identity is still
visible, it may repeat that clearance move up to three total times. The current gate's
`_scan_mm_total` is unchanged because the current spool did not move.

If the reader still sees the same left-neighbor spool identity after the third
clearance move and follow-up read, scan-jog emits an `[ERROR]`, exits through
the normal rewind path, and restores the left neighbor by the accumulated
clearance distance. It does not assign the neighbor spool to the current lane.

Both successful and aborted scan exits call `restore_left_neighbor()` after the
current gate rewind is queued:

```gcode
MMU_SELECT GATE=<left>
MMU_TEST_MOVE MOVE=-75.00 QUIET=1
M400
MMU_SELECT GATE=<current>
```

```python
def finish(gate):
    gate._scan_mode = False
    gate.__class__._active_scan_gate = None
    gate._state.miss_count = 0
    gate._run_rewind()
    # Dispatch the spool event that was suppressed while the filament was moving.
    if gate._scan_found_event is not None:
        event_type, g, uid, spool = gate._scan_found_event
        gate._scan_found_event = None
        gate._klipper.dispatch(event_type, g, uid, spool)
    gate._resume_poll_after_rewind()
```

### `rewind_and_exit(gate)` — abort path

```python
def rewind_and_exit(gate):
    gate._scan_mode = False
    gate.__class__._active_scan_gate = None
    gate._state.miss_count = 0
    gate._run_rewind()
    gate._resume_poll_after_rewind()
```

`resume_poll_after_rewind` restarts the poll timer with an extra delay equal to the rewind move duration (`scan_mm_total / speed`) so the first scheduled poll fires after the rewind is complete.

### `run_jog(gate, mm)` — jog primitive

```python
def run_jog(gate, mm):
    gcode = gate.printer.lookup_object('gcode')
    gcode.run_script("MMU_TEST_MOVE MOVE=%.2f QUIET=1" % mm)
```

`MMU_SELECT GATE=N` is issued once in `start()` before the scan timer fires. `run_jog` issues only `MMU_TEST_MOVE` since the gate context is already set. `QUIET=1` suppresses HH console output.

### `run_rewind(gate)` — rewind primitive

```python
def run_rewind(gate):
    if gate._scan_mm_total <= 0.0:
        return
    gcode = gate.printer.lookup_object('gcode')
    gcode.run_script("MMU_TEST_MOVE MOVE=%.2f QUIET=1\nM400"
                     % -gate._scan_mm_total)
```

Rewind is dead-reckoning: a negative `MMU_TEST_MOVE` of exactly `scan_mm_total`. `M400` (wait for moves) is appended so the reactor timer knows the rewind is physically complete before the next poll fires.

---

## Timer Lifecycle

| Timer | Created | Destroyed | Interval |
|---|---|---|---|
| `_poll_timer` | `__init__` (parked at NEVER) | `_handle_disconnect` | `poll_interval` (default 10 s) |
| `_scan_timer` | `start()` | `step_event()` returns NEVER | `scan_poll_interval` |

The scan timer is created anew on each scan entry. Returning `reactor.NEVER` from `step_event` parks it permanently. `_scan_mode = False` is the canonical in-flight abort flag.

---

## GateState Interaction

`step_event` calls `gate._poll()` directly — the same method the poll timer fires. `_poll()` runs the full state machine including Spoolman lookup and `GateState.process_read`. When `_poll()` returns `True` (tag found), `step_event` calls `finish()` immediately.

**Event dispatch is deferred during scan.** If a spool-changed event fires while `_scan_mode` is True (filament is still moving), `NFC_manager` caches it in `_scan_found_event` instead of dispatching immediately. `finish()` dispatches the cached event after `run_rewind()` returns, so HH and Spoolman receive the notification only after the filament is back at the parked position.

`GateState.miss_count` does **not** increment during scan ticks. `process_read()` receives `scan_mode=True` when called from within scan mode — the miss path is skipped for no-read results. A missed NFC read during a deliberate spool rotation is not an absence event.

---

## Interaction with `_hh_load_paused`

When `_poll()` identifies a tag during a scan step, `GateState.process_read` sets `current_uid` and `current_spool` but `KlipperInterface.dispatch` is suppressed — the event is cached in `_scan_found_event`. After the rewind completes, `finish()` dispatches `_NFC_SPOOL_CHANGED`; HH sets `gate_spool_id[N] > 0`. When the poll timer resumes, the first tick sees `_hh_gate_matches_current_spool()` returning True and enters the normal suspended state.

---

## Logging

Scan-jog messages follow the standard debug level conventions:

| Message | Level gate | `nfc_reader.log` | `klippy.log` |
|---|---|---|---|
| `scan mode started — chunk=Xmm max=Xmm speed=Xmm/s` | `debug >= 3` | ✅ | ❌ |
| `gate loaded; waiting for HH idle before scan` | `debug >= 3` | ✅ | ❌ |
| `HH idle; waiting 0.1s before scan-jog` | `debug >= 3` | ✅ | ❌ |
| `scan preflight — lane N gate_status=X safe/not safe` | `debug >= 3` | ✅ | ❌ |
| `scan trigger deferred: gate N already scanning` | `debug >= 3` | ✅ | ❌ |
| `starting scan-jog (max=Xmm poll=Ys)` | `debug >= 3`; console always | ✅ | ❌ |
| `scan-jog not available while reason` | warning (always) | ✅ | ✅ |
| `tag identified — rewinding Xmm` | `info` (always) | ✅ | ❌ |
| `rewind complete; gate parking handed to Happy Hare` | `info` (always) | ✅ | ❌ |
| `no tag — jogged Xmm / Xmm` | `info` (always at each step) | ✅ | ❌ |
| `print started — aborting` | warning (always) | ✅ | ✅ |
| `no tag after Xmm — rewinding` | warning (always) | ✅ | ✅ |

Set `debug: 3` to observe scan start and success. Set `debug: 4` for full poll detail during scans.

---

## Happy Hare Compatibility Notes

- `MMU_SELECT GATE=N` and `MMU_TEST_MOVE MOVE=mm QUIET=1` are standard Happy Hare v2.x commands.
- `get_speed()` reads `mmu.gear_short_move_speed` from the HH Python object to compute chunk timing. Falls back to 80 mm/s if the attribute is absent.
- `mmu.get_status()['gate_status']` values: `0` = empty, `1` = available/parked, `2` = available from buffer. Scan mode triggers only on `0 → 1`. Buffer-loaded filament (`0 → 2`) does not trigger.
- `mmu.get_status()['action']` is lowercased and compared `== 'idle'` (exact). If HH changes its action string, the guard silently prevents scan mode from starting (safe-fail direction).

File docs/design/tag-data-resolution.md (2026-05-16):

# Tag Data Resolution and Spoolman Auto-Create

**Status:** Point-in-time design snapshot  
**Branch:** woodworker-debug  
**Related:** lameandboard/rfid tag_parser reference implementation

> **Decision recorded 2026-04-29:** After completing this design, we reviewed lameandboard/rfid's `spoolman_client.py` in detail and found it already implements `auto_create_spool()`, `find_or_create_vendor()`, `find_or_create_filament()`, `build_openspool_payload()`, and SpoolmanDB density/Bambu metadata integration. Rather than porting individual methods, we decided to embed their library directly. This was enabled by relicensing the project from CC BY-NC-SA 4.0 to **GPL-3.0-or-later**, which is compatible with their GPLv3 code and consistent with the rest of the Klipper ecosystem.
>
> The design below remains valid as a specification of intended behavior and the resolution flow. Implementation will use lameandboard's client for all Spoolman CRUD operations, adapting it to our logging/debug system and retaining our `rfid_tag` UID field convention (not their `rfid_uid_N` multi-slot pattern).

---

## Requirements

1. **Feature flag required.** Full tag-data reads, payload parsing, hardware-family classification, and Spoolman auto-create must run only when explicitly enabled. The default upgrade path remains UID-only.
2. **UID-only compatibility.** When `tag_parsing: False`, the PN532 driver and manager behavior must remain compatible with the current flow: read UID, resolve UID through Spoolman, and dispatch the existing Happy Hare macros.
3. **PN532 integration support.** The PN532 driver will be extended to return target identity fields needed by the manager: UID, UID bytes, target number, ATQA/SENS_RES, SAK, and UID length.
4. **Manager chooses read strategy.** `NFCManager` must choose the tag-data read strategy from the target identity returned by the UID/anticollision read. The parser detects payload format after bytes/blocks are available; it does not choose the hardware read strategy.
5. **Read while present.** When tag parsing is enabled and a tag is detected, all configured page/block reads must happen immediately while the tag is still in front of the reader. Scan-jog, rewind, park, or later manager logic must not assume it can return to the hardware for metadata.
6. **Cache complete tag observation.** The manager must cache the full observation from the detection window: UID, target identity, raw pages or authenticated blocks when available, parser result, parse errors, and final resolution result.
7. **Conservative fallback.** If target identity is unknown, the reader does not support the needed strategy, authentication fails, parsing fails, or the tag is blank, the system falls back to UID-only resolution without disrupting the existing Spoolman path.
8. **No tag writes in this feature.** This design is read-only. Any future tag-write behavior, including writing resolved Spoolman IDs back to tags, is a separate explicitly gated feature. A future bidirectional-sync phase is an opportunity to leverage `lameandboard/rfid`'s existing write capabilities so resolved Spoolman spool IDs can be written back to writable tags. Before enabling that mode, the design should define how Spoolman and the physical tag payload stay synchronized when either side contains newer or conflicting metadata.
9. **Spoolman auto-create remains opt-in.** Parsed metadata may be used for lookup and direct Happy Hare mapping when enabled, but creating Spoolman records requires `spoolman_auto_create: True`.
10. **Keep our UID field convention.** All Spoolman UID matching and new spool creation continue to use the configured `spoolman_rfid_key`, defaulting to `rfid_tag`.

---

## Opportunity

Today the system reads only the factory UID from each NFC tag. The UID is a lookup key into Spoolman via the `rfid_tag` extra field. This is a reliable baseline, and the integration can now improve on it by using the richer metadata already present on many filament tags.

This creates two useful expansion opportunities:

1. **Tags that carry filament data** (OpenSpool NDEF JSON, Bambu MIFARE blocks, Elegoo, Creality, etc.) can provide material, color, temperature, weight, and sometimes embedded Spoolman IDs. Leveraging that data can reduce or remove manual UID registration.
2. **Spoolman-free setups** can still benefit from tag metadata. If `spoolman_url` is empty or Spoolman is unavailable, parsed filament data can be handed directly to Happy Hare.

---

## Goals

1. Parse tag payload pages or authenticated blocks to extract filament metadata and any embedded Spoolman spool ID.
2. Use embedded spool ID (when present) as the primary Spoolman key — no manual registration required for tags that carry it.
3. Fall back to existing UID-lookup path when no embedded ID is found.
4. When Spoolman is enabled but the spool is not yet there, optionally auto-create the filament and/or spool from tag metadata.
5. When Spoolman is disabled entirely, hand the parsed filament metadata directly to Happy Hare.

---

## Current State

```
tag detected
  └─ read UID only (pn532_driver)
       └─ SpoolmanClient.lookup_spool_by_uid(uid)
            ├─ match → _NFC_SPOOL_CHANGED(GATE, SPOOL_ID)
            └─ no match → _NFC_TAG_NO_SPOOL(GATE, UID)
```

Happy Hare always receives `SPOOL_ID`. Material/color is pulled from Spoolman's spool record by Happy Hare itself — we never touch it.

---

## Proposed Flow

```
tag detected
  └─ pn532_driver reads target identity
       → uid, uid_bytes, target, ATQA/SENS_RES, SAK, uid_length

       ├─ tag_parsing: False
       │    └─ UID-only resolution (current behavior)
       │
       └─ tag_parsing: True
            └─ NFCManager classifies target identity
                 ├─ NTAG / Type 2-compatible
                 │    └─ PN532 driver reads configured user pages immediately
                 ├─ MIFARE Classic-compatible
                 │    └─ lameandboard/rfid derives/selects auth keys
                 │         └─ PN532 driver authenticates sectors and reads blocks
                 └─ unknown / unsupported
                      └─ no metadata read; UID-only fallback

            └─ lameandboard/rfid parse_tag(raw_or_blocks, uid)
                 → tag metadata { uid, raw_format?, spoolman_id?,
                                  vendor?, material?, color_hex?,
                                  nozzle_temp?, bed_temp?, parse_error?, ... }

            └─ cache full observation
                 uid + target identity + raw data + parsed metadata

            ┌─────────────────────────────────────────────────┐
            │  Is Spoolman enabled?                           │
            │  (spoolman_url is non-empty and reachable)      │
            └──────────┬──────────────────────────────────────┘
                       │ Yes                       No
                       ▼                           ▼
        ┌──────────────────────────┐   ┌──────────────────────────────┐
        │ Step 1: embedded ID?     │   │ HH direct path               │
        │                          │   │ MMU_GATE_MAP with tag metadata│
        │ tag has spoolman_id?     │   │ (no Spoolman call)           │
        └──────┬───────────────────┘   └──────────────────────────────┘
               │ Yes                      No
               ▼                          ▼
  lookup by ID             Step 2: UID lookup (existing)
  GET /spool/{id}          SpoolmanClient.lookup_spool_by_uid(uid)
       │                          │
       │ found                    │ found
       └──────────┬───────────────┘
                  ▼
     _NFC_SPOOL_CHANGED(GATE, SPOOL_ID)   ← today's success path

       No match from either lookup
               ▼
        ┌──────────────────────────────┐
        │ Step 3: Auto-create enabled? │
        │ (spoolman_auto_create: True) │
        └──────┬───────────────────────┘
               │ Yes                 No
               ▼                     ▼
  Step 4: create path         _NFC_TAG_NO_SPOOL(GATE, UID)
  find or create filament          (today's no-match path)
  create spool
  → _NFC_SPOOL_CHANGED(GATE, new_spool_id)
```

When tag parsing is enabled, metadata reads are part of the tag-detection window. Resolution logic must use cached data only. It must not attempt a later page read after scan-jog rewinds or parks the spool.

---

## Read Strategy Responsibilities

The integration has three distinct responsibilities that must not be blurred:

1. **PN532 driver reads hardware.** It owns UID detection, target identity reads, NTAG/Type 2 page reads, MIFARE Classic sector authentication, and MIFARE block reads. It does not interpret filament metadata, create Spoolman records, or issue Happy Hare commands.
2. **NFCManager chooses the strategy.** It looks at the target identity returned by the UID read and chooses `ntag_type2`, `mifare_classic`, or `uid_only`. It also controls the feature flags and decides whether enhanced metadata reads are allowed.
3. **`lameandboard/rfid` supplies domain logic.** It provides parser support, Bambu/MIFARE key derivation or key-selection helpers, tag-format knowledge, and Spoolman auto-create logic. It should not directly perform Klipper I2C/SPI hardware transactions in this integration.

The required order when `tag_parsing: True` is intentionally split into two phases: the hardware-critical capture phase, then the cached-data resolution phase.

```
CAPTURE PHASE — tag must still be in front of the reader

PN532 read_target()
  → UID + ATQA/SAK/target identity
  → create/update GateState.current_tag with UID + target_info

NFCManager classify target
  → NTAG/Type2, MIFARE Classic, or UID-only fallback

If NTAG/Type2:
  PN532 read user pages immediately

If MIFARE Classic:
  adapter calls lameandboard/rfid key helper
    → sector keys or no-key reason
  PN532 authenticates sectors with those keys
  PN532 reads blocks immediately
  if key/auth/read fails → UID-only fallback

GateState.current_tag stores raw pages/blocks or fallback reason

scan-jog may continue, rewind, or park

RESOLUTION PHASE — hardware is no longer required

adapter calls lameandboard/rfid parse_tag(current_tag.raw_tag_data, uid)
  → current_tag.meta / current_tag.parse_error

resolver uses current_tag.uid + current_tag.meta
  → embedded spool_id lookup
  → UID lookup
  → optional auto-create via lameandboard/rfid Spoolman client
  → direct HH metadata path when Spoolman is disabled

current_tag.resolution records the chosen path/result

resolution uses only cached GateState.current_tag data
```

The scan-jog loop must not move the spool away from the reader between UID detection and the configured metadata read attempt. Once raw metadata has either been captured or safely fallen back to UID-only, scan-jog may continue. Parser work, Spoolman lookup, and auto-create can run from cached `current_tag` data while the gate is rewinding or after it parks, because those steps no longer need the physical tag in front of the reader.

---

## Step Details

### Step 1 — Embedded Spoolman ID

Some tag formats encode a direct Spoolman spool ID. The most common is OpenSpool JSON with a `spoolman_id` field:

```json
{"version":1,"brand":"eSUN","material":"PLA","color":"#FF5500","spoolman_id":42}
```

When the embedded parser finds this field in the NDEF payload, the adapter maps it to `current_tag.meta["spoolman_id"]`. The resolution path then calls:

```
GET /api/v1/spool/{spoolman_id}
```

A 200 response with a matching record resolves immediately — no UID scan of the spool list required. This is the fast path for pre-labeled spools.

**A missing or 404 response does not stop resolution** — fall through to Step 2.

---

### Step 2 — UID Lookup (Existing Path)

Unchanged from today. `SpoolmanClient.lookup_spool_by_uid(uid)` scans all spool records for a matching `rfid_tag` extra field value. Cache behavior is unchanged.

This step runs whenever Step 1 did not produce a confirmed match.

**Future writeback opportunity:** If UID lookup resolves a spool but the physical tag does not contain an embedded `spoolman_id`, a future bidirectional-sync feature could write the resolved spool ID back to writable tags. That would make the next read eligible for the faster embedded-ID path in Step 1 and would leverage `lameandboard/rfid`'s existing tag-write support. This is not part of the read-only integration phase and must remain behind a separate explicit writeback feature flag.

---

### Step 3 — Auto-Create Gate

Only runs when:
- `spoolman_auto_create: True` (new config key, default `False`)
- Tag data has at minimum `material` (vendor optional but improves deduplication)
- Both Steps 1 and 2 returned no match

Auto-create is intentionally opt-in. A misconfigured reader that sees random tags should not silently pollute Spoolman.

---

### Step 4 — Find or Create Filament, Then Create Spool

From `NFCManager` this should be a single adapter call into the embedded `lameandboard/rfid` Spoolman client:

```python
spool = resolver.auto_create_spool(uid=uid, tag_meta=current_tag.meta)
```

Internally, the embedded client performs the Spoolman CRUD sequence.  The NFC
integration calls the vendored top-level `auto_create_spool()` with
`uid_hex=None` so it can use the richer vendor/filament/spool creation policy
without creating the vendored `rfid_uid_1` field.  Immediately after the
vendored call returns a new spool ID, our client patches the configured
`spoolman_rfid_key` field (default `rfid_tag`) onto that spool.

```
GET /api/v1/filament?vendor={vendor}&name={material}
  ├─ match found → use existing filament_id
  └─ no match → POST /api/v1/filament  (create filament)
                  → filament_id

POST /api/v1/spool
  body: { filament_id, ... }
  → new spool_id

PATCH /api/v1/spool/{new_spool_id}
  body: { extra: { rfid_tag: uid } }

→ _NFC_SPOOL_CHANGED(GATE, new_spool_id)
```

The NFC integration should not duplicate this create/find logic. Our adapter is responsible for translating `current_tag.meta` into the library's expected input, enforcing our configured `spoolman_rfid_key`/`rfid_tag` convention, and translating errors into our logging and console-message style.

The newly created spool must get the tag UID written into its `rfid_tag` extra field so that Step 2 resolves immediately on the next scan (no re-create). If that patch fails, the integration treats the auto-create as unresolved and logs a warning rather than dispatching a spool that cannot be found again by UID.

Color, nozzle temp, bed temp, and weight are written to the filament record when present in tag data and when the filament was just created (not when reusing an existing one — we don't overwrite filament records the user may have customized).

Duplicate vendor/filament guarding is delegated to `lameandboard/rfid`'s `find_or_create_vendor()` and `find_or_create_filament()` logic. Our adapter should not add a second competing duplicate-prevention layer unless testing the vendored code exposes a specific gap.

---

### HH Direct Path (Spoolman Disabled)

When `spoolman_url` is empty, `spoolman_url: disabled`, or `spoolman_url: auto` and Moonraker reports no Spoolman URL, the system skips all Spoolman calls entirely. Tag metadata from `current_tag.meta` is passed directly into the `_NFC_SPOOL_CHANGED` macro:

```gcode
_NFC_SPOOL_CHANGED GATE=0 MATERIAL=PLA COLOR=FF5500 VENDOR=eSUN
```

The default macro sets the Happy Hare gate map directly from these values:

```gcode
MMU_GATE_MAP GATE={gate} MATERIAL={material} COLOR={color} AVAILABLE=1 QUIET=1
MMU_GATE_MAP GATE={gate} APPLY=1 QUIET=1
```

The macro must handle both the Spoolman path (where `SPOOL_ID` is present, `MATERIAL`/`COLOR` may not be) and the direct path (where `MATERIAL`/`COLOR` are present, `SPOOL_ID` is not). Klipper GCode macros will error if a referenced variable is not passed, so the default macro uses conditional blocks:

```gcode
{% if spool_id is defined %}
    MMU_GATE_MAP GATE={gate} SPOOLID={spool_id} AVAILABLE=1 SYNC=1 QUIET=1
{% else %}
    MMU_GATE_MAP GATE={gate} MATERIAL={material|default('')} COLOR={color|default('')} AVAILABLE=1 QUIET=1
{% endif %}
MMU_GATE_MAP GATE={gate} APPLY=1 QUIET=1
```

---

## Embedded Library — What We Use and How

We embed two files from `lameandboard/rfid` verbatim (GPL-3.0-or-later, compatible with our license):

| Source file | Destination | Used for |
|---|---|---|
| `extras/rfid_tag_parser.py` | `klippy/extras/nfc_gates/vendor/rfid_tag_parser.py` | Tag payload parsing, all 11 formats |
| `extras/spoolman_client.py` | `klippy/extras/nfc_gates/vendor/lameandboard_spoolman.py` | Vendor/filament/spool CRUD building blocks |

### `rfid_tag_parser.py` — drop-in, no adaptation needed

Standard library only (+ optional `pycryptodome` for Bambu, `cbor2` for OpenPrintTag). No Klipper dependencies. Entry point:

```python
from .vendor.rfid_tag_parser import parse_tag, is_parse_error

info = parse_tag(raw_bytes_or_blocks, uid_hex=uid)
```

`raw_bytes_or_blocks` is either raw NTAG user-memory bytes or an authenticated MIFARE Classic block dict. Returns a metadata dict or `None`. Logger name `rfid.rfid_tag_parser` routes through standard Python logging — no change needed.

### `lameandboard_spoolman.py` — use top-level creation, then patch our UID key

Their `auto_create_spool()` can hard-code the `rfid_uid_N` multi-slot UID convention when `uid_hex` is provided. We call it with `uid_hex=None`, then patch our configured UID field through our Spoolman client:

```python
from .vendor.lameandboard_spoolman import SpoolmanClient as LBSpoolmanClient

lb = LBSpoolmanClient(base_url=our_resolved_url, timeout=self._timeout)

spool_id = lb.auto_create_spool(current_tag.meta, uid_hex=None)
self._spoolman.set_spool_uid(spool_id, uid)
```

`our_resolved_url` comes from our existing `SpoolmanClient._resolve_base_url()` so Moonraker auto-discovery and URL normalization stay in one place.

Their `build_openspool_payload(spool_dict)` is available for future tag write-back but is not called in this read-only phase.

### What stays in our `spoolman_client.py`

Our client keeps everything it already has:
- Moonraker URL auto-discovery
- Circuit breaker
- In-memory UID cache with TTL
- `lookup_spool_by_uid()` — UID-to-spool resolution
- `lookup_spool_by_id()` — direct spool ID fetch (expose existing `_fetch_spool_detail` as public)
- `set_spool_uid()` — patches this integration's configured RFID extra field after auto-create

It does not gain vendor/filament/spool creation — those come from the embedded client.

### Adapter responsibilities

Our adapter code (in `nfc_manager.py` or a thin `tag_resolver.py`) owns NFC-Gates-specific behavior:

- translating `parse_tag()` output into `current_tag.meta`
- passing `our_resolved_url` to the embedded client so both clients share one URL-resolution result
- enforcing `spoolman_rfid_key` / `rfid_tag` on every Spoolman write
- translating embedded client errors into our debug/logging system
- keeping all of this behind `tag_parsing` and `spoolman_auto_create` flags

### GateState Refactor

Do not introduce a competing tag model unless implementation proves it is needed. Today, `GateState` already tracks the live tag identity and owns the debounce/event logic:

```python
current_uid
current_spool
process_read(uid_hex, spool_id, scan_mode=False)
```

The integration can refactor `GateState` before parser support is enabled, as long as the existing behavior and tests remain unchanged. `GateState` should remain the gate debounce/event state machine, and a new `current_tag` field should hold the richer tag observation used by future metadata reads:

```python
current_uid              # compatibility alias / shortcut for current_tag.uid
current_spool            # compatibility alias / shortcut for current_tag.spool_id
current_tag              # rich tag observation, or None
```

`current_tag` should be populated from the first UID read today, and later enriched by the second metadata read when `tag_parsing: True`:

```python
current_tag.uid              # factory UID
current_tag.spool_id         # resolved Spoolman ID, or None
current_tag.target_info      # PN532 target identity: ATQA/SAK/UID length/etc.
current_tag.raw_tag_data     # raw pages or authenticated blocks when captured
current_tag.meta             # adapted lameandboard/rfid metadata dict
current_tag.spool_identity   # optional spool-level identity from metadata
current_tag.parse_error      # parser/auth/read error summary when applicable
current_tag.resolution       # final resolution path/result for debugging
```

`spool_identity` is not the physical tag UID. It is an optional normalized value
for factory formats that expose a stable spool-level identity across multiple
physical tags on the same spool. Bambu stores this as `tray_uid`; the parser
also exposes it as `spool_identity` with a `bambu_` prefix.

With `tag_parsing: False`, `current_tag` only needs UID and resolved spool ID, matching today's behavior. Future metadata fields are additive; existing UID-only logic can ignore them.

`GateState` should remain a normal behavior-owning class, not a dataclass. It owns `process_read()`, removal debounce, event generation, and state transitions.

`current_tag` should be implemented as a dataclass-style data holder, for example `CurrentTag` or `TagObservation`. It should contain structured tag data only and no gate debounce behavior.

During the transition, keep `current_uid` and `current_spool` as compatibility fields or compatibility properties so existing code can continue to read and write them safely. `process_read()` should keep those fields and `current_tag` synchronized. Existing tests must continue to pass before any parsing capability is enabled.

### Parser Adapter

The adapter calls `lameandboard/rfid`'s parser directly:

```python
info = lameandboard_rfid.parse_tag(raw_or_blocks, uid_hex=uid)
tag_meta = adapt_lameandboard_info(uid, info)
```

`raw_or_blocks` is either raw NTAG/Type 2 user memory bytes, or an authenticated MIFARE Classic block dictionary compatible with `lameandboard/rfid`'s `parse_tag()` input. The adapter returns a metadata dict that can be stored on `current_tag.meta`.

**Format detection order:**

| Priority | Format | Detection |
|---|---|---|
| 1 | Authenticated MIFARE Classic blocks | Bambu, Creality CFS, QIDI, or other block-based formats when authenticated data is available |
| 2 | Binary NTAG/Type 2 formats | ELEGOO, Anycubic ACE, and similar raw user-memory layouts |
| 3 | NDEF MIME formats | OpenTag3D, OpenPrintTag, OpenSpool JSON |
| 4 | NDEF text/URI formats | SimplyPrint/QIDI URL, generic JSON, query params |
| 5 | Blank / unwritten tag | Empty data, all zeros, or empty NDEF wrapper returns metadata with only `uid` populated |

The embedded parser identifies the payload format after the reader has already supplied bytes or authenticated blocks. It does not decide whether the physical tag should be read as NTAG pages or MIFARE Classic blocks; that decision belongs to `NFCManager` and the reader driver.

**Blank tag behavior:** A factory-fresh NTAG tag has no user data — pages 4–N are 0x00 or an empty NDEF message (`0x03 0x00 0xFE`). Blank or unrecognized parser output is adapted into metadata with only `uid` populated. Resolution then proceeds on UID alone, which is identical to today's UID-only path:

- UID registered in Spoolman → resolves normally
- UID not registered, auto-create off → `_NFC_TAG_NO_SPOOL` (same message as today)
- UID not registered, auto-create on → no material data available, cannot create; falls through to `_NFC_TAG_NO_SPOOL`

The only overhead compared to today is reading empty pages before concluding there is nothing on them. This is unavoidable — the system cannot know a tag is blank without reading it.

### When parsing runs

Parsing is enabled when `tag_parsing: True` (default `False` initially). When disabled the driver returns UID only and the existing flow is unchanged.

When `tag_parsing: True`, the detection pass collects UID and target identity first, then immediately performs the selected metadata read while the same tag is still present. The manager caches the complete observation before scan-jog moves the spool.

- **Known UID** — metadata is still captured and cached when tag parsing is enabled, so the manager has a complete tag observation for debugging and future decision logic. Existing UID resolution may still win.
- **Unknown UID** — metadata is parsed and used for embedded ID lookup, direct Happy Hare metadata, or optional auto-create.
- **Unsupported tag type** — no metadata read is attempted; UID-only resolution continues.

The page/block read cost is paid only when `tag_parsing: True`. This is intentional: once scan-jog advances, the tag may no longer be in front of the reader, so metadata cannot be deferred safely.

---

## Configuration Changes

### `nfc_reader.cfg` additions

```ini
[nfc_gate]
# Tag data parsing
tag_parsing:          False   ; True = read tag metadata pages/blocks and parse
                              ; False = UID only (current behavior, default)

# Bambu/MIFARE authenticated rich reads
bambu_reads:          False   ; True = allow Bambu Key-A auth/read when
                              ; tag_parsing is True and pycryptodome is installed

# Spoolman auto-create (only active when tag_parsing: True and Spoolman enabled)
spoolman_auto_create: False   ; True = create filament/spool in Spoolman when
                              ; no existing match is found for a tag
```

`tag_parsing`, `bambu_reads`, and `spoolman_auto_create` can be overridden per lane in `nfc_reader_hw.cfg`.

---

## Changes to Existing Code

### `pn532_driver.py`

- Keep `read_tag()` as the UID-only compatibility method.
- Expose `read_target()` to the manager as the enhanced detection method when `tag_parsing: True`. It returns UID, UID bytes, target number, ATQA/SENS_RES, SAK, and UID length.
- Add or harden raw NTAG/Type 2 user-memory reads, using sequential `READ` commands up to `tag_max_pages`.
- Add MIFARE Classic sector authentication and block-read support as a separate reader capability. The driver receives keys from the manager/adapter and uses those keys for `InDataExchange` auth/read commands; it does not derive the keys itself. If unavailable, MIFARE Classic tags fall back to UID-only resolution with a clear debug/warning message.
- Pages/blocks and UID must be collected during the same tag presence. No later hardware read is part of the resolution ladder.

### Logging conventions

All new code in this integration must follow the existing debug level conventions:

| Level | When to use |
|---|---|
| `logger.error(...)` | Unexpected exceptions — parse_tag raised, vendor import failed |
| `logger.warning(...)` | Recoverable failures — NTAG read failed, empty read, auth failed, fallback taken |
| `logger.info(...)` at `debug >= 3` | State changes visible to the user — UID read, parse result summary, Spoolman lookup result, resolution path taken |
| `logger.debug(...)` at `debug >= 4` | Full detail — raw metadata dict, page-level read trace, every resolution step |

Console output (`self._console(...)`) is reserved for user-facing events (spool found, tag not registered). It must not be used for internal resolution steps.

---

### `nfc_manager.py`

- `NFCGate._poll_tag()` keeps the current UID-only call when `tag_parsing: False`.
- When `tag_parsing: True`, `NFCGate._poll_tag()` calls `read_target()` and passes target identity to the manager's classifier.
- New helper `_classify_tag_target(target_info)` maps ATQA/SAK/UID length to a conservative strategy: `ntag_type2`, `mifare_classic`, or `uid_only`.
- New helper `_resolve_auth_keys(current_tag)` asks the adapter/library for required MIFARE keys when the selected strategy needs authentication. This is a pre-read call to `lameandboard/rfid`. Failure to resolve keys is not fatal; it records the reason and falls back to UID-only resolution.
- The selected strategy performs the metadata read immediately and updates `GateState.current_tag` with UID, target identity, raw pages or authenticated blocks, and any read/auth failure reason.
- After the raw capture phase, a second adapter call invokes `lameandboard/rfid.parse_tag()` using cached `current_tag.raw_tag_data`; this fills `current_tag.meta` or `current_tag.parse_error`.
- Resolution runs from cached `GateState.current_tag`; it must not ask the reader for metadata later.
- New helper `_spoolman_enabled()` — returns `True` when `spoolman_url` is non-empty and not `disabled`.
- `_dispatch_spool_changed()` accepts optional tag metadata so metadata params can be forwarded to the macro when Spoolman is disabled.

### `spoolman_client.py`

- No new CRUD methods added here. Creation is delegated to the embedded `lameandboard_spoolman.py`.
- Expose `_fetch_spool_detail` as public `lookup_spool_by_id(spool_id)` — needed for Step 1 (embedded ID resolution).
- Continue to own URL resolution, circuit breaker, cache, and UID lookup. The resolved base URL is shared with the embedded client at call time so both use the same discovered URL.

### `vendor/lameandboard_spoolman.py` (vendored verbatim)

- Copied from `lameandboard/rfid extras/spoolman_client.py` at a pinned source commit into `klippy/extras/nfc_gates/vendor/`.
- Used only for `find_or_create_vendor()`, `find_or_create_filament()`, and `create_spool()`.
- `auto_create_spool()` is present in the file but **not called** — it encodes the `rfid_uid_N` convention we don't use.
- Constructor receives `base_url` from our client's `_resolve_base_url()`.

### `vendor/rfid_tag_parser.py` (vendored verbatim)

- Copied from `lameandboard/rfid extras/rfid_tag_parser.py` at a pinned source commit into `klippy/extras/nfc_gates/vendor/`.
- No changes needed. `parse_tag(raw, uid_hex)` is called directly from the manager adapter.

---

## Resolution Result Summary

| Scenario | Spoolman call | HH receives |
|---|---|---|
| Spoolman disabled, tag has metadata | None | `SPOOL_ID=-1 MATERIAL=X COLOR=Y` |
| Spoolman disabled, UID only | None | nothing (existing `_NFC_TAG_NO_SPOOL`) |
| Spoolman enabled, embedded ID resolves | GET /spool/{id} | `SPOOL_ID=N` |
| Spoolman enabled, UID resolves | GET /spool list | `SPOOL_ID=N` |
| Spoolman enabled, no match, auto-create off | None | `_NFC_TAG_NO_SPOOL` |
| Spoolman enabled, no match, auto-create on, has metadata | POST filament + spool | `SPOOL_ID=new_N` |
| Spoolman enabled, no match, auto-create on, UID only | None | `_NFC_TAG_NO_SPOOL` |

---

## Open Questions

1. **Target classification table** — the current implementation has a conservative table: `SAK & 0x08` selects MIFARE Classic, `SAK == 0x00` with a common UID length selects NTAG/Type-2, and everything else falls back UID-only. Hardware validation should tighten this only from observed PN532 target data.

---

## Implementation Order

1. Copy `rfid_tag_parser.py` and `spoolman_client.py` from `lameandboard/rfid` into `klippy/extras/nfc_gates/vendor/` as `rfid_tag_parser.py` and `lameandboard_spoolman.py`. Add an empty `vendor/__init__.py`. Record the source commit SHA in a `VENDORED.md` at repo root. Both files carry their original GPLv3 headers.
2. Extend `GateState` with `current_tag` and add the parser adapter around `lameandboard/rfid.parse_tag()`.
3. Extend `pn532_driver.py` so the manager can request target identity and raw NTAG/Type 2 memory reads behind `tag_parsing`.
4. Add conservative target classification in `nfc_manager.py`: NTAG/Type 2, MIFARE Classic, or UID-only fallback.
5. Add PN532 MIFARE Classic authenticated block-read support as a gated capability. If this misses the first implementation pass, MIFARE tags remain UID-only.
6. Embed/wrap `lameandboard/rfid` Spoolman client for direct ID lookup and auto-create while preserving `rfid_tag`.
7. Implement NFCManager's spool resolution process using cached `current_tag` data only. The manager should try the resolution paths in this order:
   - If `current_tag.meta` contains an embedded Spoolman spool ID, look up that spool ID first.
   - If no spool was resolved by embedded ID, look up the tag UID using the existing `rfid_tag`/`spoolman_rfid_key` path.
   - If Spoolman is enabled, no existing spool was found, `spoolman_auto_create` is enabled, and the tag metadata has enough filament information, call the `lameandboard/rfid` auto-create path.
   - If Spoolman is disabled but tag metadata has material/color/vendor information, dispatch that metadata directly to Happy Hare.
   - If none of the above resolves a spool or usable metadata, fall back to the existing UID-only no-spool behavior.
8. Add config keys: `tag_parsing`, `tag_max_pages`, and `spoolman_auto_create`.
9. Update macros and docs for direct metadata dispatch when Spoolman is disabled.
10. Add tests for UID-only compatibility, NTAG page reads, parser adapter, target classification, auto-create gating, and UID-only fallback.

---

*Copyright (C) 2026 WoodWorker. Licensed under [GPL-3.0-or-later](https://www.gnu.org/licenses/gpl-3.0.html) — see [LICENSE](../../LICENSE).*

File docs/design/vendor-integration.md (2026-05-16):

# Vendor Integration — Logic Model

**Branch:** `lameandboard---integration`  
**Implemented:** 2026-04-30  
**Related:** [tag-data-resolution.md](tag-data-resolution.md), [VENDORED.md](../../VENDORED.md)

This document describes how the `lameandboard/rfid` library is integrated — what it provides, how it is called, and how data flows from a physical NFC tag through to Happy Hare.

---

## What the vendor library provides

Two files are vendored verbatim from `lameandboard/rfid` into `klippy/extras/nfc_gates/vendor/`:

| File | Purpose |
|---|---|
| `rfid_tag_parser.py` | Parses raw NTAG/MIFARE bytes into a filament metadata dict. Supports 11+ tag formats (OpenSpool, Bambu, Elegoo, Creality, Anycubic, etc.) |
| `lameandboard_spoolman.py` | Spoolman CRUD client — `find_or_create_vendor()`, `find_or_create_filament()`, `create_spool()` |

Both files carry their original GPLv3 headers. Neither is modified. The source commit is pinned in `VENDORED.md`.

---

## How the library is loaded

Imports are lazy and wrapped in `try/except` inside `tag_handler.py`. The vendor package is on `sys.path` via a path fix applied at module import time so Klipper's sandboxed extras loader can find it.

```
klippy/extras/nfc_gates/
├── vendor/
│   ├── __init__.py
│   ├── rfid_tag_parser.py       ← vendored, parse_tag() entry point
│   └── lameandboard_spoolman.py ← vendored, Spoolman CRUD entry points
├── tag_handler.py               ← adapter layer: tag classification, hardware capture, resolution ladder
├── gate_state.py                ← per-gate debounce state machine, CurrentTag, DIRECT_METADATA_SPOOL
├── klipper_interface.py         ← reactor-thread GCode macro dispatcher
├── nfc_manager.py               ← config, polling lifecycle, get_status()
└── spoolman_client.py           ← our UID cache/circuit-breaker client
```

Import pattern in `tag_handler.py`:

```python
try:
    from .vendor.rfid_tag_parser import parse_tag, is_parse_error
    from .vendor.lameandboard_spoolman import SpoolmanClient as LBSpoolmanClient
    _VENDOR_AVAILABLE = True
except ImportError:
    _VENDOR_AVAILABLE = False
```

If the vendor files are absent, `tag_parsing` falls back to UID-only mode. Bambu MIFARE reads additionally require `pycryptodome` in the Klipper Python venv (installed by `install.sh`).

---

## Config flags

| Key | Default | Effect |
|---|---|---|
| `tag_parsing` | `False` | Enable full tag-content reads and metadata parsing |
| `bambu_reads` | `False` | Enable authenticated MIFARE reads for Bambu factory spools (requires `pycryptodome`) |
| `spoolman_auto_create` | `False` | Allow the plugin to create filament/spool records in Spoolman from tag metadata |

`tag_parsing: False` keeps the original UID-only behavior. All vendor calls are gated on this flag.

A warning is logged at init if `bambu_reads: True` with `tag_parsing: False` — the MIFARE path is never reached in that combination.

---

## Tag parsing pipeline

When `tag_parsing: True` and a tag is detected:

```
PN532 reads target identity
  → UID + ATQA + SAK + uid_length

NFCManager classifies target
  ├─ SAK & 0x08 → MIFARE Classic  (Bambu, Creality CFS, QIDI)
  ├─ SAK == 0x00 → NTAG / Type-2  (OpenSpool, Elegoo, Anycubic, generic)
  └─ unknown → UID-only fallback

NTAG/Type-2 path:
  PN532 reads user pages 4 → tag_max_pages (default 16, covers NTAG213/215/216)
  → raw bytes stored in current_tag.raw_tag_data

MIFARE Classic path (bambu_reads: True only):
  vendor key helper derives or selects Bambu sector keys
  PN532 authenticates sectors and reads blocks
  → block dict stored in current_tag.raw_tag_data
  auth/read failure → UID-only fallback

Both paths complete while tag is physically present.
Scan-jog must not move the spool between UID detection and raw read completion.

parse_tag(current_tag.raw_tag_data, uid_hex=uid)
  → metadata dict: { material, color_hex, min_temp, max_temp,
                     bed_temp, spoolman_id?, brand?, spool_identity?, ... }
  stored in current_tag.meta

Parser runs from cached data — hardware no longer required.
```

The metadata dict field names are the vendor library's output names. The adapter in `tag_handler.py` reads them by key and does not transform them before storing on `current_tag.meta`.

`spool_identity` is an optional parser-supplied, spool-level identity string. It is distinct from the physical NFC tag UID: a single factory spool may carry multiple physical tags with different UIDs but the same spool identity. For Bambu tags this is derived from the structured `tray_uid` as `bambu_<tray_uid>`.

---

## Resolution ladder

After parse, `NFCGate._resolve_spool(uid)` works through these steps in order:

```
Step 1 — Embedded Spoolman ID
  current_tag.meta has 'spoolman_id'?
  → GET /api/v1/spool/{spoolman_id}
  → found: use this spool_id  ✓
  → 404 or missing: continue

Step 2 — UID lookup (existing path, always runs)
  SpoolmanClient.lookup_spool_by_uid(uid)
  → found: use this spool_id  ✓
  → not found: continue

Step 3 — Auto-create (spoolman_auto_create: True only)
  tag has 'material' in meta?
  → LBSpoolmanClient.find_or_create_vendor(brand)
  → LBSpoolmanClient.find_or_create_filament(vendor_id, material, color, temp)
  → LBSpoolmanClient.create_spool(filament_id)
  → SpoolmanClient.set_spool_uid(new_spool_id, uid)   ← writes our rfid_tag key
  → SpoolmanClient.clear_cache()                       ← force re-poll on next scan
  → use new_spool_id  ✓
  → failed: continue

Step 4 — Spoolman disabled, metadata available  (DIRECT_METADATA_SPOOL sentinel)
  spoolman_url empty/disabled AND meta has material or color
  → return DIRECT_METADATA_SPOOL sentinel
  → KlipperInterface dispatches NAME/MATERIAL/COLOR/TEMP directly to macro
  → no spool_id assigned

Step 5 — UID-only fallback
  → _NFC_TAG_NO_SPOOL(GATE, UID)
```

`current_tag.resolution` records which step succeeded:

| Resolution | Meaning |
|---|---|
| `embedded_id` | Spoolman spool ID was in the tag payload |
| `uid_lookup` | Matched by UID in Spoolman extra field |
| `auto_create` | New spool created in Spoolman from tag metadata |
| `metadata_direct` | Spoolman disabled; metadata sent directly to HH |
| `unresolved` | UID not found in Spoolman, no auto-create |

---

## DIRECT_METADATA_SPOOL sentinel

When Spoolman is disabled and the tag carries metadata, there is no spool ID to assign. Rather than returning `None` (which means "no tag"), the resolver returns the module-level sentinel object `DIRECT_METADATA_SPOOL`.

`GateState` stores this on `current_spool`. All downstream code that checks `current_spool is not None` correctly sees it as "something is assigned". `get_status()` recognises the sentinel and returns `spool_id: -1` with `resolution: 'metadata_direct'`.

---

## KlipperInterface dispatch

`KlipperInterface.dispatch()` (adapter between the polling loop and Klipper GCode) calls `_run_gcode()` which builds the macro invocation string:

**Spoolman path** (`spool_id` is an integer):

```
_NFC_SPOOL_CHANGED GATE=0 SPOOL_ID=26 UID=04AABBCC
```

**Metadata-direct path** (`spool_id is None`, meta dict present):

```
_NFC_SPOOL_CHANGED GATE=0 NAME=eSUN_PLA MATERIAL=PLA COLOR=#FF5500 TEMP=220 UID=04AABBCC
```

Rules applied to the metadata path:
- `NAME` uses `material_detail` or `material`, prefixed with brand/vendor/tag format when present
- `MATERIAL` and `COLOR` are only included when non-empty (omitting an empty param avoids broken GCode)
- `TEMP` uses `meta['min_temp']` (lower bound of the print window = recommended extruder temp), only included when present
- `VENDOR` is not passed — HH has no `VENDOR` param; vendor/brand display comes from HH's own Spoolman enrichment when a spool ID is set
- Special characters in string values are sanitised via `_macro_value()`: spaces → underscores, non-alphanumeric/`#`/`.`/`_` stripped

---

## Happy Hare macro

`_NFC_SPOOL_CHANGED` in `nfc_macros.cfg` branches on whether `SPOOL_ID` was passed:

```jinja
{% if params.SPOOL_ID is defined %}
    MMU_GATE_MAP GATE={gate} SPOOLID={spool_id} AVAILABLE=1 SYNC=1 QUIET=1
{% else %}
    MMU_GATE_MAP GATE={gate}
      {% if name     %} NAME={name}{% endif %}
      {% if material %} MATERIAL={material}{% endif %}
      {% if color    %} COLOR={color}{% endif %}
      {% if temp     %} TEMP={temp | int}{% endif %}
      AVAILABLE=1 QUIET=1
{% endif %}
MMU_GATE_MAP GATE={gate} APPLY=1 QUIET=1
```

- `SYNC=1` on the Spoolman path pushes the spool assignment back to Spoolman so the spool's location field stays current
- `APPLY=1` on a second call activates the gate (HH loads the filament profile)
- NAME/MATERIAL/COLOR/TEMP are each omitted from the MMU_GATE_MAP call when not present in params

---

## Spoolman clients — two clients, one URL

There are two Spoolman HTTP clients in play:

| Client | File | Owns |
|---|---|---|
| Our client | `spoolman_client.py` | URL auto-discovery (Moonraker), circuit breaker, UID cache, `lookup_spool_by_uid()`, `lookup_spool_by_id()`, `set_spool_uid()` |
| Vendor client | `lameandboard_spoolman.py` | `find_or_create_vendor()`, `find_or_create_filament()`, `create_spool()` |

The vendor client is instantiated only during auto-create, receiving the URL that our client already resolved. Both clients therefore use the same Moonraker-discovered URL. Our client does not gain vendor/filament/spool creation logic; the vendor client does not know about our UID cache or circuit breaker.

---

## get_status() fields

`NFCGate.get_status()` exposes gate state to Moonraker/Fluidd/macros:

| Field | Type | Description |
|---|---|---|
| `gate` | int | Gate index |
| `tag_present` | bool | True when a tag UID is currently on the gate |
| `spool_id` | int | Resolved Spoolman spool ID, or -1 when no spool assigned |
| `uid` | str | Current tag UID hex string, or '' |
| `failed` | bool | True when the PN532 hardware has entered a failed state |
| `resolution` | str | Internal path taken (debug/diagnostic use; consumers should use `tag_present` and `spool_id`) |

The three meaningful states a consumer should branch on:

| `tag_present` | `spool_id` | State |
|---|---|---|
| `False` | `-1` | Empty gate — no tag |
| `True` | `-1` | Tag present, no Spoolman spool (metadata-direct or uid-only) |
| `True` | `N` | Tag resolved to spool N |

---

## pycryptodome dependency

Bambu MIFARE reads use HKDF key derivation, which requires `pycryptodome`. `install.sh` targets the Klipper Python venv (`~/klippy-env/` or `/home/*/klippy-env/`) so the library is available in the same environment where `tag_handler.py` runs. `uninstall.sh` removes it from the same venv.

`bambu_reads: False` (default) skips all MIFARE authentication. `pycryptodome` is not required when Bambu reads are disabled.

---

## Updating the vendored library

See `VENDORED.md` for the pinned source commit and manual update instructions. A GitHub Action runs weekly and opens a PR automatically when upstream changes either vendored file. Review any diff against `tag_handler.py` adapter code before merging — the adapter keys into specific field names from the parser output.

---

*Copyright (C) 2026 WoodWorker. Licensed under [GPL-3.0-or-later](https://www.gnu.org/licenses/gpl-3.0.html).*

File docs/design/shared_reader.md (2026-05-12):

# Design: Shared Reader

> Status: In progress
> Scope: No IRQ/data-ready pin support in this phase.

---

Implementation status and audit notes live in [shared_reader_implementation.md](shared_reader_implementation.md).
User-facing console and log output is defined in
[message_definition.md](../shared/message_definition.md).

---

## Goal

Add one NFC reader inside the MMU body that is **not tied to an EMU lane**.
The reader acts as a staging point for the next manually loaded spool:

1. User taps a tag on the hidden MMU reader.
2. NFC resolves the tag to a Spoolman spool ID, creating the spool first if
   `spoolman_auto_create` is enabled and the tag carries enough metadata.
3. NFC gives user feedback through LEDs.
4. User loads a spool through the normal MMU/pre-gate path.
5. Happy Hare assigns the staged spool ID to whichever gate is preloaded next.

Happy Hare already has the desired primitive:

```gcode
MMU_GATE_MAP NEXT_SPOOLID=<spool_id>
```

If a gate is preloaded within Happy Hare's timeout window after that command,
HH assigns that spool ID to the loaded gate. The shared reader should use that
mechanism instead of trying to determine the destination gate itself.

---

## Non-goals

- Do not make the shared reader part of the EMU lane reader set.
- Do not add PN532 IRQ/data-ready support yet.
- Do not scan-jog from the shared reader.
- Do not infer gate assignment by inspecting NFC gate polling state.
- Do not duplicate Spoolman create/lookup logic already used by lane readers.
- Do not duplicate the existing NFC reader timer, read, resolve, debounce, or
  debug command machinery.
- Do not call Happy Hare Python internals directly. Use HH's public GCode
  command surface.

---

## Key Decision

Use a normal `NFCGate` instance for the physical reader and put it in shared
mode. The reader is configured as `[nfc_gate shared]` with `shared: true`.
No `mmu_gate` value is needed or accepted from the user — the shared reader has
no Happy Hare gate assignment. An internal sentinel (255) is used only for
PN532Driver and GateState logging and is never passed to Happy Hare.

**No per-lane readers are required.** A shared-only installation needs only the
base `[nfc_gate]` section (optional, for Spoolman config) and the
`[nfc_gate shared]` section. No `[nfc_gate lane0]` or similar sections are
needed.

The shared reader has no physical EMU lane, so its dispatch behavior differs
from a normal lane:

```text
lane reader:
  physical gate -> read tag -> resolve spool -> assign that same gate

shared reader:
  existing NFCGate poll -> resolve spool -> remember pending spool
  preload hook -> stage NEXT_SPOOLID
```

That means the shared reader only needs to know:

- the most recently scanned spool ID
- whether that staged spool is still within the timeout window

It does **not** need to know:

- which gate is currently loaded
- which gate is about to preload
- whether an EMU lane reader is paused
- whether a lane reader has cached NFC state

The preload hook is primarily a timing signal. NFC should wait until Happy Hare
reports that a pregate-triggered preload is about to start, then issue
`MMU_GATE_MAP NEXT_SPOOLID=<id>` if a valid pending spool exists. Happy Hare
still decides which gate receives that staged spool.

`shared` is the NFC object name. Scan-jog edge detection and HH gate-map
matching are disabled for this reader. All user interaction goes through
`NFC_SHARED`.

---

## Proposed Config

The shared reader is configured as a regular `[nfc_gate ...]` section with a
single shared flag. This avoids a second config namespace and lets the
reader share the existing PN532 driver, Spoolman client, tag parser, logging,
status, debug, and polling controls.

**Minimal config — only hardware addressing and the shared flag are required:**

```ini
[nfc_gate shared]
i2c_mcu: mmu
i2c_bus: i2c1
i2c_address: 0x24
shared: true
startup_polling: 1
```

`mmu_gate` and `scan_enabled` are not written and are not accepted from the
user when `shared: true`. `scan_enabled` is forced to `false` (no physical EMU
lane). `mmu_gate` is replaced by an internal sentinel and is never user-facing.
`startup_polling` remains an explicit user choice.

Full config with all optional keys shown:

```ini
[nfc_gate shared]
i2c_mcu: mmu
i2c_bus: i2c1
i2c_address: 0x24
shared: true
startup_polling: 1
poll_interval: 3.0
shared_pending_timeout: 120.0
shared_read_timeout:    120.0
shared_tag_read_effect: mmu_RFID_read
shared_spool_ready_effect: mmu_RFID_ready
shared_tag_unresolved_effect: mmu_RFID_unresolved
```

Keys:

| Key | Default when `shared: true` | Meaning |
|---|---:|---|
| `shared` | `false` | Enables shared dispatch. Setting to `true` forces `scan_enabled: false` and removes the `mmu_gate` requirement. |
| `mmu_gate` | N/A — not user-configurable | An internal sentinel is used. `mmu_gate` is not read from config when `shared: true`. |
| `scan_enabled` | `false` (forced) | Always `false` for shared reader; scan-jog cannot run without a physical EMU lane. |
| `startup_polling` | `0` | Set to `1` to poll at Klipper boot. Explicit user choice — not implied by `shared`. |
| `poll_interval` | `3.0` | Poll interval while the reader is active. 3 s is imperceptible for a human loading spools; see Reactor Cooperation. |
| `shared_pending_timeout` | `120.0` | Seconds a scanned spool remains eligible for the next preload. Governs the window from tag scan to `PRELOAD_CHECK` firing. |
| `shared_read_timeout` | `120.0` | Seconds polling may remain active after `READ=1` without a valid tag resolving. No effect when polling starts via `startup_polling` or PRELOAD_CHECK auto-restart. |
| `shared_tag_read_effect` | `''` | HH LED effect name for tag-detected feedback. Leave empty to skip LED feedback. |
| `shared_spool_ready_effect` | `''` | HH LED effect name for ready-to-load feedback after a real Spoolman spool ID is resolved. |
| `shared_tag_unresolved_effect` | `''` | HH LED effect name for unresolved UID feedback. |

### Config Validation

```text
if shared == true:
    mmu_gate     → not read from config; internal sentinel used
    scan_enabled → always false; user value ignored
    all shared_* keys are optional with the defaults above
    only one nfc_gate section may have shared == true
    NFC GATE= mux command is NOT registered (NFC_SHARED is the sole interface)
```

### Implementation

Read `shared` first in `NFCGate.__init__`, validate uniqueness, then assign
gate and scan_enabled without reading them from config:

```python
self._shared = config.getboolean('shared', False)
if self._shared:
    for existing in _lane_instances:
        if getattr(existing, '_shared', False):
            raise config.error(
                "nfc_gate [%s]: only one shared reader may be configured" % self._name)

# Gate number: required for lane readers; internal sentinel for shared.
# Not user-configurable for shared — never passed to Happy Hare.
if self._shared:
    self._gate = _SHARED_GATE_SENTINEL   # module constant = 255
else:
    self._gate = config.getint('mmu_gate', minval=0)

# scan_enabled: forced false for shared (no physical EMU lane for jog)
if self._shared:
    self._scan_enabled = False
else:
    self._scan_enabled = config.getboolean('scan_enabled',
                                           d.scan_enabled if d else True)
```

In `_handle_connect`, skip `NFC GATE=` mux registration for shared:

```python
if not self._shared:
    self._gcode.register_mux_command(
        cmd='NFC', key='GATE', value=str(self._gate),
        func=self.cmd_NFC, ...)
```

---

## Config File Layout
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

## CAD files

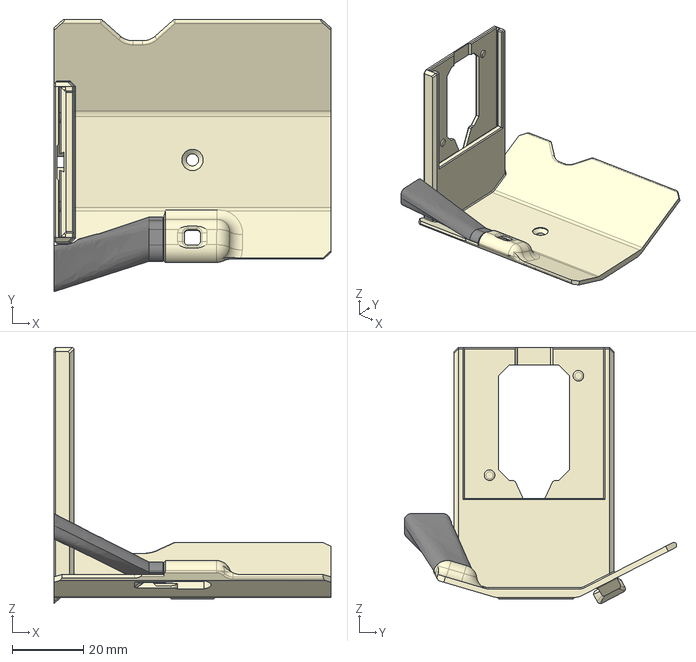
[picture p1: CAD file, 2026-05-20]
NFC Mounting Bracket/LED_holder_with_NFC_Slide_in_Mount.step
78.0 x 76.7 x 72.2 mm

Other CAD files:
NFC Mounting Bracket/LED_holder_with_NFC_Slide_in_Mount.stl

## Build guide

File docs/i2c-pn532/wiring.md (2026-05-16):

# Wiring the PN532

[← README](../../Readme.md) | [Next: Install →](../shared/install-uninstall.md)

For per-lane EMU readers, each filament gate gets **one PN532 wired directly to
that gate's EBB42**. There is no shared bus across the per-lane readers — each
reader lives on its own lane MCU's I2C bus.

The optional shared reader is the exception: it is a single PN532 mounted inside
the MMU body and configured separately in `nfc_reader_shared.cfg`. It still
must be wired to **some Klipper MCU's available I2C bus** — for example the MMU
MCU, a toolhead MCU, or another controller already declared with an `[mcu ...]`
section. The installer can write `i2c_mcu` / `i2c_bus` into
`nfc_reader_shared.cfg`, but it does not create or validate that physical bus;
you must pick real SDA/SCL pins supported by that MCU and wire the PN532 there.
See [Shared Reader](../shared/shared-reader.md) for that wiring/config flow.

```
lane0 EBB42  ←I2C→  PN532 (gate 0)
lane1 EBB42  ←I2C→  PN532 (gate 1)
lane2 EBB42  ←I2C→  PN532 (gate 2)
  ...
```

---

## Before You Wire Anything

> [!IMPORTANT]
> **Set the PN532 to I2C mode first, before connecting any wires.** The mode is selected by two jumpers or DIP switches on the PN532 board (labeled SEL0/SEL1, or sometimes A0/A1). If the mode is wrong, the reader will not respond on the I2C bus — and the symptoms look exactly like a wiring fault.

| Mode | SEL0 | SEL1 |
|---|:---:|:---:|
| SPI | 0 | 0 |
| **I2C ← set this** | **1** | **0** |
| UART / HSU | 0 | 1 |

Set **SEL0 = 1, SEL1 = 0**. Check your board's silkscreen — some boards number the switches in reverse, or label them differently. When in doubt, check the NXP PN532 datasheet (UM10232), Table 3.

---

## Soldering the PN532

The PN532 antenna pads are fragile — the copper ring on the top (antenna) side will lift off the board if overheated. Always solder from the back.

**Method:**

1. Insert the wire from the **back** of the board so it pokes through the hole toward the antenna side.
2. Apply the iron to the back of the board. Let solder pool up on the back pad.
3. Feed enough solder that the pool flows **through the hole** and wets the antenna-side ring — you should see a small fillet appear on the top.
4. Remove heat immediately once the solder flows through. Lingering heat is what lifts the antenna-side ring.

> [!WARNING]
> **Never apply the iron directly to the antenna-side pad.** The copper ring on the top of the board is bonded to a thin substrate and will delaminate with sustained heat. If the ring lifts, the mechanical connection is gone even if the hole still looks filled.

A proper joint: solder pool visible on the back, small filled fillet on the antenna side, wire cannot be pulled out by hand.

---

## Pin Connections

Connect each PN532 to its lane's EBB42 using these four wires:

```
EBB42 Pin       →    PN532 Module
──────────────────────────────────
PB3  (I2C SCL)  →    SCL
PB4  (I2C SDA)  →    SDA
3V3             →    VCC  (or the 3.3V pad if your board has both)
GND             →    GND
```

> [!WARNING]
> **3.3V logic only on SDA and SCL.** Some PN532 breakout boards accept 5V on the VCC pin through an onboard regulator, but the I2C signal lines must be 3.3V. The EBB42 is a 3.3V device. Never connect 5V to PB3 or PB4.

The matching Klipper config for these pins:

```ini
[nfc_gate lane0]
i2c_mcu: lane0
i2c_bus: i2c3_PB3_PB4
```

---

## I2C Address

The PN532 I2C address is **fixed at `0x24` (decimal `36`)** by the chip — it cannot be changed. The two pads/jumpers on the breakout board (SEL0/SEL1, sometimes labeled A0/A1) select the **communication protocol**, not the address. For I2C you must have SEL0=1, SEL1=0 (see the mode table above).

The address is set in `nfc_reader.cfg`:

```ini
[nfc_gate]
i2c_address: 36    ; fixed — 36 = 0x24, do not change
```

---

## Sharing the Bus with a BME280

The EBB42 typically has a BME280 temperature/humidity sensor on the same PB3/PB4 bus. This is fine — the PN532 (`0x24`) and BME280 (`0x76`) have different addresses and coexist without conflict.

> [!NOTE]
> If the BME280 worked before you added the PN532 and now fails, it is almost always a physical issue — the PN532 is in SPI or UART mode and disrupting the bus, or there is a wiring problem. See [Troubleshooting: BME280 fails after PN532 is added](troubleshooting.md#bme280-fails-after-pn532-is-added).

---

## Pull-up Resistors

I2C needs pull-up resistors on SDA and SCL. Most PN532 breakout boards include 10kΩ pull-ups, and the EBB42 also has its own. These typically work fine together.

If you add more boards (each with their own pull-ups), the parallel resistance drops and can cause marginal signaling:

- 2× 10kΩ boards in parallel → 5kΩ — fine
- 3× boards → ~3.3kΩ — usually fine
- 6+ boards → ~1.7kΩ — may be too strong

If you suspect pull-up issues: remove or bridge (disable) the PN532 board's onboard resistors and rely on the MCU's pull-ups alone.

---

## Wire Length

Keep wires short for initial bring-up — under 20cm if possible. Longer cables add capacitance that rounds signal edges, which makes marginal timing worse.

Once confirmed working, cables up to ~50cm are usually fine at 400kHz. If you see intermittent failures with longer cables, drop the I2C speed:

```ini
[nfc_gate lane0]
i2c_speed: 100000    ; 100kHz instead of 400kHz
```

---

## Bring-Up Order

Follow this sequence to avoid chasing phantom failures:

1. Confirm Happy Hare sees the lane MCU normally (no PN532 connected yet)
2. If a BME280 is fitted, confirm it reads correctly before touching anything
3. Set the PN532 DIP switches to I2C mode (SEL0=1, SEL1=0)
4. Connect VCC and GND
5. Connect SDA and SCL
6. Restart Klipper
7. Run `NFC GATE=0 INIT=1`
8. If INIT passes, run `NFC GATE=0 SCAN=1` with a tag nearby

If the BME280 breaks only after the PN532 is connected, the fault is physical — mode selection, swapped SDA/SCL, or pull-up interaction. It is not a Spoolman or Happy Hare issue.

---

*Copyright (C) 2026 WoodWorker. Licensed under [GPL-3.0-or-later](https://www.gnu.org/licenses/gpl-3.0.html) — see [LICENSE](../../LICENSE).*

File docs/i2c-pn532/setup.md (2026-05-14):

# First-Time Setup

[← Install](../shared/install-uninstall.md) | [Spoolman Setup →](../shared/spoolman-integration.md)

This guide assumes you have:
- [Wired the PN532](wiring.md) readers and set them to I2C mode
- [Installed the software](../shared/install-uninstall.md)
- Rebuilt and flashed Klipper firmware on every lane MCU

If you skipped any of those, do them first.

---

## Step 1 — Add Includes to `printer.cfg`

Add these three lines in this exact order:

```ini
[include nfc/nfc_reader.cfg]
[include nfc/nfc_macros.cfg]
[include nfc/nfc_reader_hw.cfg]
```

`nfc_reader.cfg` must come first — it defines the base `[nfc_gate]` section that each `[nfc_gate laneN]` in `nfc_reader_hw.cfg` inherits from. Reversing the order causes a Klipper config error on startup.

---

## Step 2 — Configure Spoolman

Edit `~/printer_data/config/nfc/nfc_reader.cfg`:

```ini
[nfc_gate]
spoolman_url:      auto
spoolman_rfid_key: rfid_tag
```

| Setting | Value | When to use |
|---|---|---|
| `spoolman_url: auto` | Reads URL from Moonraker | Use this when `moonraker.conf` has a `[spoolman]` section |
| `spoolman_url: http://host:7912` | Direct URL | Use when testing, or if `auto` isn't working |
| `spoolman_rfid_key: rfid_tag` | Extra field name | Must match what you create in Spoolman Settings |

See [Spoolman Integration](../shared/spoolman-integration.md) — you need to create the extra field in Spoolman and register each tag UID before spool detection will work.

---

## Step 3 — Configure Lane Hardware

Edit `~/printer_data/config/nfc/nfc_reader_hw.cfg`. The default file has four lanes; adjust to match your printer:

```ini
[nfc_gate lane0]
mmu_gate:   0
i2c_mcu:    mmu0
i2c_bus:    i2c3_PB3_PB4

[nfc_gate lane1]
mmu_gate:   1
i2c_mcu:    mmu1
i2c_bus:    i2c3_PB3_PB4
```

| Key | Required | Value |
|---|:---:|---|
| `mmu_gate` | Yes | Happy Hare gate number (0-based integer) |
| `i2c_mcu` | Yes | Klipper MCU name — must match an `[mcu laneN]` in your config |
| `i2c_bus` | Yes | I2C bus name on that MCU — use `i2c3_PB3_PB4` for PB3/PB4 on EBB42 |

> [!NOTE]
> `i2c_mcu` must exactly match the MCU name Klipper uses. These names come from Happy Hare's `mmu_hardware.cfg`, typically `lane0`, `lane1`, etc. A mismatch causes a Klipper startup error.

> [!IMPORTANT]
> **Temperature sensor I2C bus must match.** If your lane MCU has a thermistor or temperature sensor on I2C (e.g. an SHT3x), configure it on the **same hardware I2C bus** as the PN532 — the same `i2c_bus` value used in `[nfc_gate laneN]` or the base `[nfc_gate]`. Klipper's software-emulated I2C (`i2c_software_*`) is not compatible with the PN532 driver; hardware I2C is required for both devices.

All polling, timing, and logging settings are inherited from the base `[nfc_gate]` in `nfc_reader.cfg`. Override per-lane only if you need different behavior on a specific lane:

```ini
[nfc_gate lane2]
mmu_gate:   2
i2c_mcu:    mmu2
i2c_bus:    i2c3_PB3_PB4
debug:      2              ; verbose logging on this lane only
```

---

## Step 4 — Restart Klipper

```bash
sudo systemctl restart klipper
```

Watch the log for NFC startup messages:

```bash
tail -f ~/printer_data/logs/nfc_reader.log
```

Errors at this stage are almost always config typos or a missing/mismatched lane MCU name.

---

## Step 5 — Verify Each Reader

### 1. Check all gates

```gcode
NFC_STATUS
```

Expected with no tags loaded:
```
NFC gate status  (4 gates configured):
  Gate 0  [lane0]:  empty
  Gate 1  [lane1]:  empty
  Gate 2  [lane2]:  empty
  Gate 3  [lane3]:  empty
```

### 2. Watch the startup console output

When Klipper connects, each lane initialises automatically and reports to the console. Look for:

```
✅ NFC[lane0]: ready.  HH seed: spool_id=42  Startup polling is enabled; first poll in 0.0s.
```

or, if the gate was empty in Happy Hare:

```
✅ NFC[lane0]: ready.  HH reports gate empty  Run NFC GATE=0 READ=1 to start polling.
```

**The HH seed line is important.** It means NFC_Manager read Happy Hare's gate map on startup and pre-loaded the lane cache with the spool HH already knows about. The first poll will verify the physical tag matches that spool — if it does, no redundant dispatch is sent to Happy Hare. If the spool was swapped while Klipper was down, the mismatch is detected and `_NFC_SPOOL_CHANGED` fires normally.

If Happy Hare wasn't ready when the NFC init ran, the seed step is skipped. Run `NFC_HH_SYNC_CACHE` to manually re-seed all lanes from the current HH gate map.

### 3. Initialize a lane manually

```gcode
NFC GATE=0 INIT=1
```

This runs the PN532 `GetFirmwareVersion` and `SAMConfiguration` handshake. Expected output:
```
NFC[lane0]: reader OK
```

If it fails, check [Troubleshooting](troubleshooting.md).

### 4. Hardware scan

Hold an NFC tag near the reader, then:

```gcode
NFC GATE=0 SCAN=1
```

The UID prints to the console. This is a raw hardware read — no Spoolman lookup, no Happy Hare update.

### 5. Full pipeline test

With a registered tag (see [Spoolman Integration](../shared/spoolman-integration.md)):

```gcode
NFC GATE=0 POLL=1
```

Expected console output:
```
NFC gate 0: spool 42 detected (UID 04AABBCCDD). Sending to Happy Hare.
```

This runs the full chain: PN532 read → Spoolman lookup → state update → Happy Hare macro. If this works, the pipeline is complete.

---

## Step 6 — Enable Background Polling

Once a lane works end-to-end, start automatic polling:

```gcode
NFC GATE=0 READ=1
```

To start all lanes, run `READ=1` for each. Polling runs at the `poll_interval` (default: 30 seconds).

**Optional: automatic polling on startup.**
To have lanes start polling automatically after Klipper boots, set `startup_polling: 1`. The shipped `nfc_reader_hw.cfg` staggers the per-lane startup delays by 0.5 seconds so all readers don't poll simultaneously:

```ini
[nfc_gate lane0]
startup_polling:    1
startup_poll_delay: 0.0

[nfc_gate lane1]
startup_polling:    1
startup_poll_delay: 0.5

[nfc_gate lane2]
startup_polling:    1
startup_poll_delay: 1.0

[nfc_gate lane3]
startup_polling:    1
startup_poll_delay: 1.5
```

---

## Next Steps

- [Spoolman Integration](../shared/spoolman-integration.md) — register your tag UIDs
- [Commands & Macros](../shared/klipper-functions.md) — full command reference
- [Configuration Reference](../shared/configuration.md) — tune polling, logging, and timing

---

*Copyright (C) 2026 WoodWorker. Licensed under [GPL-3.0-or-later](https://www.gnu.org/licenses/gpl-3.0.html) — see [LICENSE](../../LICENSE).*

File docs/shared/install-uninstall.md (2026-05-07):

# Install & Uninstall

[← README](../../Readme.md) | [Wiring](../i2c-pn532/wiring.md) | [Setup →](../i2c-pn532/setup.md)

---

## How the Install Works

The installer creates **symlinks** — it does not copy Python files into the Klipper directory. This means:

- Updating is just `git pull` — the new code is live immediately, no file copy needed
- Config files in `~/printer_data/config/nfc/` are yours — the installer never overwrites sections you have already edited
- Running `bash install.sh` again after an update is always safe

**What gets created:**

```
~/klipper/klippy/extras/nfc_gate.py    →  symlink → repo/klippy/extras/nfc_gate.py
~/klipper/klippy/extras/nfc_gates/     →  symlink → repo/klippy/extras/nfc_gates/
~/printer_data/config/nfc/nfc_reader.cfg
~/printer_data/config/nfc/nfc_macros.cfg
~/printer_data/config/nfc/nfc_reader_hw.cfg
```

Config files use a non-destructive merge: if a section already exists in your file, it is left alone. Only missing sections are appended.

---

## Install

### Step 1 — Flash Lane MCU Firmware

> [!CAUTION]
> Do this before anything else. The PN532 driver communicates directly with the EBB42 MCU firmware over I2C. If the host Klipper and the MCU firmware are on different versions, I2C reads fail with errors that look like hardware faults.
>
> Build and flash Klipper firmware for every lane MCU / EBB42 that will carry a PN532 before you run the installer.

### Step 2 — Clone the Repository

SSH to the Pi:

```bash
cd ~
git clone --filter=blob:none --sparse git@github.com:<your-github-username>/NFC-Reader.git emu-nfc-reader
cd ~/emu-nfc-reader
git sparse-checkout set klippy config 
```

The sparse checkout skips any large binary assets and keeps only what the Pi and Klipper need.

### Step 3 — Run the Installer

```bash
bash install.sh
```

The installer prints what it creates. If it cannot find the Klipper extras directory or the printer config directory, it exits with an error before making any changes.

### Step 4 — Add Includes to `printer.cfg`

Open `~/printer_data/config/printer.cfg` and add these three lines **in this exact order**:

```ini
[include nfc/nfc_reader.cfg]
[include nfc/nfc_macros.cfg]
[include nfc/nfc_reader_hw.cfg]
```

Order is required. `nfc_reader.cfg` defines the base `[nfc_gate]` section that each lane section inherits from. Including the lane file first causes a Klipper startup error.

### Step 5 — Configure Spoolman

Edit `~/printer_data/config/nfc/nfc_reader.cfg`:

```ini
[nfc_gate]
spoolman_url:      auto
spoolman_rfid_key: rfid_tag
```

**`spoolman_url: auto`** works when Moonraker has a `[spoolman]` section configured. Use a direct URL if you need to point at a specific instance:

```ini
spoolman_url: http://192.168.1.50:7912
```

See [Spoolman Integration](spoolman-integration.md) for how to create the extra field and register UIDs.

### Step 6 — Configure Lane Hardware

Edit `~/printer_data/config/nfc/nfc_reader_hw.cfg`. The default file has four lanes — adjust the MCU names and gate numbers to match your Happy Hare setup:

```ini
[nfc_gate lane0]
mmu_gate:   0
i2c_mcu:    lane0
i2c_bus:    i2c3_PB3_PB4
```

`i2c_mcu` must exactly match the MCU name in your Happy Hare config (from `mmu_hardware.cfg`), typically `mmu0`, `mmu1`, etc.

> [!IMPORTANT]
> **Temperature sensor I2C bus must match.** If your lane MCU also has a thermistor or temperature sensor connected over I2C (e.g. an SHT3x), it must be configured on the **same hardware I2C bus** as the PN532. Set `i2c_bus` in your temperature sensor section to the same value as the `i2c_bus` in the matching `[nfc_gate laneN]` section (or the base `[nfc_gate]` if all lanes share one bus). Using a different bus, or using the Klipper software-emulated I2C bus (`i2c_software_*`), will cause collisions or read failures on both devices. Hardware I2C is required.

See [Configuration Reference](configuration.md) for all available settings.

### Step 7 — Restart and Verify

```bash
sudo systemctl restart klipper
```

```gcode
NFC_STATUS
```

Expected output with no tags loaded:

```
NFC gate status  (4 gates configured):
  Gate 0  [lane0]:  empty
  Gate 1  [lane1]:  empty
  Gate 2  [lane2]:  empty
  Gate 3  [lane3]:  empty
```

If you see errors, check [Troubleshooting](../i2c-pn532/troubleshooting.md).

---

## Moonraker Update Manager

Add this block to `~/printer_data/config/moonraker.conf` so Fluidd/Mainsail can update the NFC reader alongside Klipper:

```ini
[update_manager emu_nfc_reader]
type:             git_repo
path:             ~/emu-nfc-reader
origin:           git@github.com:<your-github-username>/NFC-Reader.git
primary_branch:   main
managed_services: klipper
install_script:   install.sh
```

Restart Moonraker:

```bash
sudo systemctl restart moonraker
```

> [!NOTE]
> The update manager runs `install.sh` automatically after pulling. Since the Python extras are symlinks, new code is live immediately after the pull. You still need to **manually rebuild and flash lane MCU firmware** when a Klipper MCU protocol change is included in an update — the update notes will say so.

---

## Updating

```bash
cd ~/emu-nfc-reader
git pull
bash install.sh
sudo systemctl restart klipper
```

If the update notes mention a Klipper MCU protocol change, rebuild and flash each lane MCU before restarting Klipper.

---

## Uninstall

```bash
cd ~/emu-nfc-reader
bash uninstall.sh
```

The uninstaller:

1. Removes the `nfc_gate.py` symlink from Klipper extras
2. Removes the `nfc_gates/` symlink from Klipper extras
3. Removes legacy `~/pn532_scan.py` if an older installer placed it there
4. Moves `~/printer_data/config/nfc/` to `nfc_removed_<timestamp>/` (your config is preserved, not deleted)
5. Restarts Klipper

**Manual steps after uninstalling** — the uninstaller cannot edit your config files:

Remove these three lines from `printer.cfg`:
```ini
[include nfc/nfc_reader.cfg]
[include nfc/nfc_macros.cfg]
[include nfc/nfc_reader_hw.cfg]
```

Remove the update manager block from `moonraker.conf`, then restart Moonraker:
```bash
sudo systemctl restart moonraker
```

Delete the config backup when you no longer need it:
```bash
rm -rf ~/printer_data/config/nfc_removed_*
```

---

*Copyright (C) 2026 WoodWorker. Licensed under [GPL-3.0-or-later](https://www.gnu.org/licenses/gpl-3.0.html) — see [LICENSE](../../LICENSE).*

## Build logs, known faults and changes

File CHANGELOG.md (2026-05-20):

# Changelog

All notable changes to the EMU NFC Gate Reader are documented here.
Format follows [Keep a Changelog](https://keepachangelog.com/en/1.1.0/).

---

## [05/19/2026] - WoodWorker

### Shared Reader Preload — Spool ID Timing Fix

- `MMU_GATE_MAP NEXT_SPOOLID` is now staged in Python immediately when the NFC tag resolves to a spool, rather than inside the `_NFC_SHARED_PRELOAD` GCode macro. Previously the macro ran AFTER Happy Hare had already finalized the gate map entry for the loaded gate, so the spool ID was never applied to the active gate and it displayed `Id: n/a`.
- For auto-created spools, `MMU_SPOOLMAN REFRESH=1` is also dispatched at resolution time (before `NEXT_SPOOLID`) so Happy Hare knows about the new spool before the hint is staged.
- Removed the now-redundant `MMU_GATE_MAP NEXT_SPOOLID` and `MMU_SPOOLMAN REFRESH` lines from `_NFC_SHARED_PRELOAD`; the macro now only handles validation (`PRELOAD_CHECK`) and commit (`PRELOAD_COMMIT`).
- If Happy Hare already shows the staged shared-reader spool assigned to a loaded gate, `_NFC_SHARED_PRELOAD` now treats that as success and commits the pending NFC read without clearing the Happy Hare gate map. This fixes same-lane eject/read/reinsert flows where the spool briefly loaded and then the gate was reset to `Empty` / `Id: n/a`.
- When no spool is pending at preload time (either nothing was tapped or the UID was unresolved), `_NFC_SHARED_PRELOAD` now clears the target gate's map to `SPOOLID=-1 COLOR=FFFFFF55` before firing the `force_spool_id` advisory. Previously the gate retained the previous spool's color and ID so the EMU showed the wrong spool instead of the shadowed unknown state.

### LED Effects

- `mmu_RFID_read` changed from 3 flashes to 1 flash on tag scan, differentiating it clearly from `mmu_RFID_bypass_ready` (3 flashes = bypass spool confirmed).
- Shared reader events now flash **all MMU gate exit LEDs simultaneously** using `define_on: gates, exit`. Happy Hare creates a whole-chain effect (`unit0_mmu_RFID_read_exit`) that targets every exit LED at once; the shared reader uses this instead of a single per-gate effect.
- Bypass-ready/shared-ready LED effects are now scheduled to stop after 4 seconds when used for immediate bypass spool confirmation, so the confirmation flash does not run indefinitely.
- The shared-reader 80% pending-timeout warning now defaults to `mmu_RFID_warning`, switches from the ready LED to the warning LED at the warning point, and re-arms itself for the actual timeout so expiry cleanup cannot be missed.
- When a shared-reader pending spool expires, NFC now stops the warning LED, issues `MMU_GATE_MAP QUIET=1` to restore Happy Hare steady-state LEDs, and restarts shared polling so another spool can be scanned immediately.

### Shared Reader Installer

- Shared-reader installs no longer inject `shared_led_segment` into generated config; users can own that setting directly in `nfc_reader_shared.cfg`.
- Re-running the installer in shared-reader mode now skips `nfc_reader_hw.cfg` lane-section merging so pure shared installs do not unexpectedly append lane sections.
- Shared-reader installs now update only the selected hardware/startup keys in `[nfc_gate shared]`, preserving user-edited LED settings and comments.
- The installer no longer regenerates the full shared-reader config on every shared install. It now uses targeted `set_config_value` updates for `i2c_mcu`, `i2c_bus`, `shared`, and `startup_polling`.
- Added `detect_mmu_led_unit()` to the installer. It reads `[mmu_leds <name>]` from `mmu_hardware.cfg` and exposes the real unit name so the post-install summary shows the correct whole-chain effect name (e.g., `unit0_mmu_RFID_read_exit`) instead of a hardcoded placeholder.

### Shared Reader LEDs

- `shared_led_segment: exit` keeps the whole-segment LED behavior (`unit0_mmu_RFID_read_exit`).
- `shared_led_segment: gate` restores the legacy single-lane LED behavior (`mmu_RFID_read_exit_N`).
- `shared_led_segment` is normalized to lowercase at load time, so values like `Gate` and `EXIT` resolve consistently.
- `nfc_reader_shared.cfg` now documents `shared_led_segment` as an LED target selector: `exit`/`entry`/`status` target a whole segment, while `gate` targets the legacy single lane.

### Happy Hare Bypass

- Shared-reader spool resolution now detects Happy Hare bypass mode (`printer.mmu.tool == -2`) and immediately sets Moonraker's active Spoolman spool through `_NFC_SHARED_BYPASS_SPOOL_CHANGED`.
- When bypass is active, the shared reader does not stage `NEXT_SPOOLID` or wait for the Happy Hare preload hook; normal shared preload behavior is unchanged for MMU gates.

### Config Compatibility

- Replaced raw CSS hex colors in `_NFC_SPOOL_CHANGED` console messages with named colors so Klipper's config/template parser does not treat `#` as a comment marker and halt during startup.
- Unknown/no-spool NFC metadata now uses `COLOR=FFFFFF55` consistently, matching the scan-unresolved placeholder color.
- Shared-reader preload transaction warnings now use the standard NFC console color tags instead of raising Klipper command errors, avoiding red `!! Error running _NFC_SHARED_PRELOAD` wrappers for nonfatal bridge warnings.

### Console Output and Logging Consistency

- All log message prefixes standardized to `NFC[name]: ` across every module (`nfc_manager.py`, `shared_preload.py`, `tag_handler.py`, `scan_jog.py`). Previously the format varied between `nfc_gate: [name] `, `nfc_gate: `, and bare messages.
- Switched console dispatch from `RESPOND PREFIX="NFC" MSG="..."` to `RESPOND TYPE=command MSG="..."`. The `PREFIX` form prepended `//` to every message in Fluidd/Mainsail; `TYPE=command` delivers the message body without any Klipper-added prefix, so `[OK]`, `[WARN]`, and `[ERROR]` color tags render cleanly.
- `shared_preload.py` fully converted from `gcmd.respond_info()` to `logger.info/warning/error()`. All `PRELOAD_CHECK`, `PRELOAD_COMMIT`, and `PRELOAD_CLEAR_ASSIGNED` feedback now routes through the shared logger so the three output destinations (nfc_reader.log, klippy.log forwarding, and Klipper console) are always in sync.

### Log Rotation and Pruning

- Fixed archive accumulation: `_prune_old_archives` now runs at every Klipper startup, not only when the midnight-crossing `_rotate` path fires. Previously, Klipper restarts before midnight would rename the old log file but never prune, so archives built up indefinitely.
- Retention remains 7 days / 7 archives; the bug was the pruning never ran, not the threshold.

### Sync Workflow

- Updated `sync-public.yml` to exclude all older NFC gate hanger files from the public repo sync. Only `LED_holder_with_NFC_Bambu_height v3.step` is now published; `LED_holder_NFC_Guard_Bambu_height.*`, `LED_holder_with_NFC_Bambu_height.stl/.step`, `LED_holder_NFC_Guard.*`, and `LED_holder_No_cover_with_NFC.*` are excluded from rsync and explicitly removed via `rm -f` so stale copies are cleaned up in the public repo.

### Tests

- Added regression coverage for shared LED target naming, including whole-segment and legacy single-gate modes.
- Added regression coverage for shared-reader bypass detection and immediate active-spool assignment.
- Added installer checks to keep `shared_led_segment` out of generated shared config and prevent shared-only installs from merging lane hardware sections.
- Added a macro config guard so `action_respond_info` lines do not use raw CSS hex color literals.
- Added LED flash-count assertions for `mmu_RFID_read` (1 flash) and `mmu_RFID_ready` (continuous).

---

## [05/18/2026]

### Shared Reader Improvements

- Added full shared-reader command coverage through `NFC_SHARED`, including help, status, summary, cancel, replace, LED test, cache sync, polling, scan, and raw poll actions.
- `NFC_SHARED HELP=1` now documents the required `=1` action flag style so commands match Klipper's parser and avoid malformed bare commands.
- Shared-reader installs now include the base `nfc_reader.cfg` along with `nfc_reader_shared.cfg`, so the standard NFC commands and shared commands are both available after install.
- Shared-reader polling uses the scan-jog reader interval, not the slower base polling interval. The config comments now call this out so tuning the shared reader is less mysterious.
- The shared reader now prints a green `[OK]` line as soon as a tag is successfully read and staged, before the later Happy Hare preload messages.
- `nfc_reader_shared.cfg` now defaults `i2c_mcu: mmu` so the most common wiring works without editing the hardware config.

### LED Behavior

- Fixed indefinitely looping unresolved-tag strobe — it now plays a fixed number of flashes and stops cleanly.
- `mmu_RFID_ready` (green strobe) now persists continuously while a spool is staged and waiting to load; previously it blinked twice and stopped.
- Added `mmu_RFID_warning` amber strobe: plays when the pending timeout is 80% elapsed, giving the user a visible countdown before the spool is dropped.
- Amber warning strobe stops exactly when the pending timeout expires — no overshoot.
- After all NFC effects finish, HH gate LEDs are restored via `MMU_GATE_MAP QUIET=1` only when no spool is pending, preventing HH's gate repaint from killing the active ready effect mid-wait.
- On pending timeout, polling always restarts automatically (equivalent to issuing `NFC_SHARED REPLACE=1`).

### Klipper Deadlock Fix

- Eliminated a class of Klipper deadlocks caused by calling `run_script()` from inside GCode command handlers. All LED, respond, and HH gate-map calls that originate from GCode handlers are now deferred via `register_async_callback`. Affected commands: `NFC_SHARED LED_TEST`, `REPLACE`, `CANCEL`, `CLEAR`, `PRELOAD_CLEAR_ASSIGNED`.

### Happy Hare Preload Behavior

- Fixed the pure shared-reader stale assignment path. If Happy Hare still has a spool assigned to a gate when the shared reader stages that same spool, NFC now clears the stale Happy Hare gate assignment and gets ready for the next tag.
- Hybrid installs are still protected: when per-lane readers are present, the shared reader does not overwrite or clear legitimate per-lane assignments.
- `NFC_SHARED PRELOAD_CLEAR_ASSIGNED=1` now receives the assigned gate number so the automatic cleanup can target the correct Happy Hare gate.
- `force_spool_id` no longer throws a Klipper command error when no spool is staged. It now shows one red `[ERROR]` console advisory instead of duplicated `!!` error lines.
- `_NFC_SHARED_PRELOAD` macro cross-checks `gate_status` when evaluating already-assigned spools — a gate with status 0 (filament absent) is no longer treated as occupied, fixing the case where a spool ejected from a gate with no per-lane reader left a stale HH assignment that blocked future loads of the same spool.

### Console Output

- All NFC console messages now route through the logger rather than inline `RESPOND` GCode calls, eliminating `echo:` format output and removing a second source of deadlocks.
- Standardized console tag colors:
  - `[OK]` renders green.
  - `[WARN]` renders yellow.
  - `[ERROR]` renders red text without forcing a Klipper error unless the command truly fails.
- Reduced duplicate shared-reader warnings by keeping recovered stale-assignment details in the internal log and showing only one concise console warning.
- Replaced stop-sign precondition glyphs with `[ERROR]` for clearer, consistent console messages.

### Documentation

- README and quick-install guide updated with the correct Happy Hare hook parameter: `variable_user_post_preload_extension: '_NFC_SHARED_PRELOAD'` in `mmu_macro_vars.cfg`.
- Install instructions now list the required config includes for shared-reader installs.
- Command reference updated to cover `NFC_SHARED` commands users are expected to run day-to-day.

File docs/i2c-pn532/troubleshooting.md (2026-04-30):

# Troubleshooting

[← README](../../Readme.md) | [Setup](setup.md) | [Expert Debug →](../shared/expert-low-level-i2c-debugging.md)

---

## Start Here: MCU Firmware

> [!CAUTION]
> **The most common source of PN532 failures is stale lane MCU firmware.**
>
> If you updated the Klipper host but didn't rebuild and flash the EBB42 firmware, the MCU and host are running different protocol versions. I2C failures from this look exactly like hardware problems — bad wiring, wrong mode, broken module.
>
> **Rebuild and flash every lane MCU. Then try again.**

---

## Klipper Won't Start — Config Errors

### `Unknown config section 'nfc_gate'`

The NFC Python module didn't load. Check that the symlinks exist:

```bash
ls -la ~/klipper/klippy/extras/nfc_gate.py
ls -la ~/klipper/klippy/extras/nfc_gates/
```

If missing, run the installer again:
```bash
cd ~/emu-nfc-reader && bash install.sh
```

---

### `Section 'nfc_gate lane0' defined before 'nfc_gate' base section`

The includes in `printer.cfg` are in the wrong order. It must be:

```ini
[include NFC/nfc_reader.cfg]     ← first
[include NFC/nfc_macros.cfg]
[include NFC/nfc_reader_hw.cfg]    ← last
```

---

### `Option 'i2c_mcu' in section 'nfc_gate lane0' is not a valid config option`

Same cause as above — the base `[nfc_gate]` section wasn't loaded before the lane section. Fix the include order.

---

## PN532 Not Responding

### `PN532 did not respond`

The reader isn't answering on the I2C bus at all.

Check in this order:

1. **I2C mode** — SEL0=1, SEL1=0 on the PN532 DIP switches. This is the most common mistake.
2. **Voltage** — VCC is 3.3V (or 5V through onboard regulator if your board supports it, but SDA/SCL must be 3.3V)
3. **GND** — shared between PN532 and lane MCU
4. **SDA/SCL not swapped** — PB3=SCL, PB4=SDA on the EBB42
5. **`i2c_mcu` name** — matches exactly what Klipper uses (e.g. `lane0`, not `mcu_lane0`)
6. **`i2c_address`** — is `36` (hex `0x24`) unless you changed the address pads
7. **MCU firmware** — rebuilt and flashed to match the host Klipper version

Then try:
```gcode
NFC GATE=0 INIT=1
```

Still failing? Go to [Expert: Low-Level I2C Debugging](../shared/expert-low-level-i2c-debugging.md).

---

### `Unable to obtain 'i2c_read_response' response`

Klipper asked the MCU for an I2C read and got no reply.

Most common causes:

| Cause | Fix |
|---|---|
| Stale MCU firmware | Rebuild and flash |
| PN532 in wrong mode | Check DIP switches (SPI/UART mode accepts wiggled lines but won't produce I2C responses) |
| PN532 not ready yet | Increase `transceive_delay` to `0.500` |
| SDA/SCL swapped | Swap them |
| Another I2C device stuck | Check if BME280 is holding the bus |

**Quick test:** If `INIT=1` succeeds but polling produces this error, the issue is timing. Try:
```ini
[nfc_gate]
transceive_delay: 0.500
```

If `INIT=1` fails immediately, the bus is not functional — check wiring and mode selection first.

---

## BME280 Fails After PN532 Is Added

The BME280 (address `0x76`) and PN532 (address `0x24`) share the PB3/PB4 bus without conflict. If the BME280 worked before and breaks after the PN532 is connected:

| Symptom | Likely cause |
|---|---|
| BME280 fails on Klipper start | PN532 is in SPI or UART mode — it's disrupting the bus |
| BME280 works, fails after first INIT | PN532 power issue — voltage droop pulling SDA/SCL low |
| BME280 intermittent | Excessive pull-up current or marginal wiring |
| BME280 never works with PN532 connected | SDA/SCL short or wrong pin assignment |

**Quick check:** Disconnect the PN532 completely. If the BME280 recovers, the fault is physical — the PN532 is disrupting the bus. Check mode selection first.

---

## Tag Detected But No Spool Found

The hardware is working — the PN532 read the tag. The Spoolman lookup failed.

```gcode
NFC GATE=0 POLL=1
```

Check:

1. **`spoolman_url`** — visit it in a browser from the Pi: `curl http://yourhost:7912/api/v1/spool`
2. **`spoolman_rfid_key`** — must match the extra field name in Spoolman **exactly** (case-sensitive)
3. **UID is on the spool record**, not the filament record
4. **No typos in the UID** — copy-paste from the console, don't transcribe by hand

Enable verbose logging to see the full HTTP exchange:

```ini
[nfc_gate]
debug:             2
console_output:    True
console_log_level: info
```

Restart Klipper, run `POLL=1`, and read the log.

---

## False Spool Removals

Gate declares the spool removed while it's still physically there.

**Cause:** The reader is occasionally missing reads (tag angle, vibration, RF environment), and `absent_threshold` is too low.

Default settings require 3 consecutive misses (~90s) before removal:
```ini
poll_interval:    30
absent_threshold: 3
```

If you're still getting false removals, raise the threshold:
```ini
absent_threshold: 5    ; ~150s before removal at default interval
```

---

## Happy Hare Not Updating

NFC is detecting tags and looking up spools, but Happy Hare's gate map isn't changing.

**Test the macro directly** — no hardware needed:

```gcode
_NFC_SPOOL_CHANGED GATE=0 SPOOL_ID=42 UID=04AABBCCDD
```

- **If this updates Happy Hare:** the macro is fine. The problem is upstream — a polling or Spoolman issue.
- **If this doesn't update Happy Hare:** check `nfc_macros.cfg` and Happy Hare command compatibility.

Common macro issues:

- Wrong `MMU_GATE_MAP` parameter syntax for your Happy Hare version
- Macro was accidentally deleted or commented out
- Happy Hare is in a state that rejects `MMU_GATE_MAP` (e.g. mid-print with gate locks)
- `spoolman_support: push` is not set in Happy Hare, so `SYNC=1` does nothing

---

## Diagnostic Command Summary

```gcode
NFC_STATUS                    ; all gates — current state
NFC GATE=0 STATUS=1       ; one gate
NFC GATE=0 INIT=1         ; re-initialize the PN532
NFC GATE=0 SCAN=1         ; one raw read, no state machine or Spoolman
NFC GATE=0 POLL=1         ; one complete cycle, watch for console output
```

For deeper investigation, enable expert debug mode:

```ini
[nfc_gate]
low_level_debug:   True
console_output:    True
console_log_level: info
```

Then:
```gcode
NFC GATE=0 HELP=1    ; lists all available debug commands
```

See [Expert: Low-Level I2C Debugging](../shared/expert-low-level-i2c-debugging.md) for the complete step-by-step manual sequence.

---

*Copyright (C) 2026 WoodWorker. Licensed under [GPL-3.0-or-later](https://www.gnu.org/licenses/gpl-3.0.html) — see [LICENSE](../../LICENSE).*

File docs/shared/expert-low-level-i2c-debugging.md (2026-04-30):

# Expert: Low-Level PN532 I2C Debugging

[← Back to README](../../Readme.md) | [Troubleshooting](../i2c-pn532/troubleshooting.md)

---

> [!WARNING]
> ## Expert Section — Read This First
>
> The commands in this section send raw bytes directly to the PN532 over I2C. They **bypass the normal state machine** entirely. Sending the wrong sequence or leaving a step half-finished can put the PN532 into a state where normal polling fails until the MCU power cycles or Klipper restarts.
>
> **Use these commands only:**
> - During initial bring-up of a new PN532 reader when normal `INIT=1` fails.
> - When you have exhausted normal troubleshooting and need to observe exactly what the bus is doing.
>
> **Do not leave `low_level_debug: True` enabled during printing.**

---

## Enabling Expert Mode

In `nfc_reader.cfg`:

```ini
[nfc_gate]
low_level_debug:   True
console_output:    True
console_log_level: info
```

Restart Klipper. When `low_level_debug` is enabled, Klipper starts cleanly but **the PN532 is not initialized**. The driver skips the wake sequence and SAMConfiguration entirely so no driver-initiated bus traffic interferes with your manual commands. The log will confirm this:

```
init: gate 0 (PN532) low_level_debug enabled — skipping wake and SAMConfiguration
```

You must run the manual init sequence (Phase 1 + Phase 2 below) before any tag read commands will work. Then ask for the command list:

```gcode
NFC GATE=0 HELP=1
```

This prints the full manual init sequence with the exact commands to paste, in order.

---

## What Expert Mode Exposes

Expert mode ports the bring-up workflow from the original `PN_CONSOLE` diagnostic tool into Klipper GCode. Each `STEP=` command executes one discrete PN532 bus transaction and reports exactly what was sent and what came back, before and after.

### Transparency output format

Every command prints:

```
NFC[lane0]: FIRMWARE WRITE before: 00 00 FF 02 FE D4 02 2A 00
NFC[lane0]: FIRMWARE WRITE after:  OK
NFC[lane0]: NEXT: NFC GATE=0 STEP=FIRMWARE_ACK
```

- **before**: the bytes that are about to be sent.
- **after**: the result (`OK`, the raw bytes read, or an error).
- **NEXT**: the next command to paste when this step succeeded.

This "paste the next command" pattern comes from the original console bring-up flow, where you run one command at a time and observe the result before proceeding.

---

## PN532 I2C Protocol Background

Understanding what you are looking at requires knowing the PN532 frame format.

### Frame structure

**Write frame (host → PN532):**

```
00 00 FF  LEN  LCS  TFI  CMD  [params]  DCS  00
```

**Read frame (PN532 → host):**

```
STATUS  00  00  FF  LEN  LCS  TFI  CMD  [data]  DCS  00
```

| Field | Meaning |
|---|---|
| `STATUS` | First byte of every I2C read. `0x01` = ready, `0x00` = busy (PN532 still processing). |
| `LEN` | Number of bytes in the data field (TFI + CMD + payload). |
| `LCS` | Length checksum: `(-LEN) & 0xFF`. LEN + LCS = 0 mod 256. |
| `TFI` | Transport Frame Identifier. `0xD4` = host→PN532, `0xD5` = PN532→host. |
| `CMD` | Command code. Response code is `CMD + 1`. |
| `DCS` | Data checksum: `(-sum(data_field)) & 0xFF`. |

### ACK frame

After every command write, the PN532 sends an ACK before it processes the command. The ACK frame is:

```
00 00 FF 00 FF 00
```

When read over I2C (including the status byte at the front):

```
01 00 00 FF 00 FF 00
```

The leading `01` is the STATUS byte (ready). The ACK itself is the remaining 6 bytes.

### PN532 command codes

| Command | Code | Purpose |
|---|---|---|
| `GetFirmwareVersion` | `0x02` | Verify PN532 is alive, get firmware version |
| `SAMConfiguration` | `0x14` | Configure Security Access Module (required before tag reads) |
| `InListPassiveTarget` | `0x4A` | Detect ISO14443A tag and return UID |
| `InRelease` | `0x52` | Release/deselect the current target |

---

## Manual Init Sequence

> [!IMPORTANT]
> **Phase 1 and Phase 2 are mandatory.** The PN532 is not initialized when Klipper starts in expert mode. You must complete both phases before tag detection (Phase 3) or any other read commands will work.

Run one command at a time. Wait for the response before running the next. If any step fails, do not proceed — diagnose the failure at that step.

### Phase 1: Wake and firmware check

```gcode
NFC GATE=0 STEP=WAKEUP
NFC GATE=0 STEP=READY
NFC GATE=0 STEP=FIRMWARE_WRITE
NFC GATE=0 STEP=FIRMWARE_ACK
NFC GATE=0 STEP=FIRMWARE_READY
NFC GATE=0 STEP=FIRMWARE_RESPONSE
```

**What each step does:**

| Step | Bus operation | Expected result |
|---|---|---|
| `WAKEUP` | Writes `0x00` to nudge the PN532 transport out of power-down mode | No response needed |
| `READY` | Reads 1 byte | `01` = ready |
| `FIRMWARE_WRITE` | Writes the `GetFirmwareVersion` command frame | `OK` |
| `FIRMWARE_ACK` | Reads 7 bytes | `01 00 00 FF 00 FF 00` |
| `FIRMWARE_READY` | Polls the STATUS byte until `01` | `01` |
| `FIRMWARE_RESPONSE` | Reads the full firmware response | `01 00 00 FF 06 FA D5 03 ...` containing IC, Ver, Rev, Support bytes |

If `FIRMWARE_WRITE` succeeds but `FIRMWARE_ACK` returns wrong bytes or errors, the problem is in the write→ACK round trip: timing, MCU firmware version, or I2C bus quality.

### Phase 2: SAM configuration

```gcode
NFC GATE=0 STEP=SAM_WRITE
NFC GATE=0 STEP=SAM_ACK
NFC GATE=0 STEP=SAM_READY
NFC GATE=0 STEP=SAM_RESPONSE
```

`SAMConfiguration` sets the PN532 to normal mode (no SAM involvement). It must succeed before `InListPassiveTarget` will work.

### Phase 3: Tag detect (optional — requires Phase 1 + 2 complete)

With the PN532 initialized, you can test tag detection:

```gcode
NFC GATE=0 STEP=PASSIVE_WRITE
NFC GATE=0 STEP=PASSIVE_ACK
NFC GATE=0 STEP=PASSIVE_READY
NFC GATE=0 STEP=PASSIVE_RESPONSE LEN=30
```

Hold a tag near the reader before running `PASSIVE_WRITE`. The `PASSIVE_RESPONSE` bytes will contain the UID if a tag was found.

---

## Step Reference

| Step | PN532 operation | What it sends / reads |
|---|---|---|
| `WAKEUP` | Nudge transport | Writes `0x00` |
| `READY` | Read STATUS byte | Reads 1 byte. Expects `01`. |
| `FIRMWARE_WRITE` | `GetFirmwareVersion` command | Writes full PN532 frame for command `0x02` |
| `FIRMWARE_ACK` | Read ACK for firmware command | Reads 7 bytes. Expects `01 00 00 FF 00 FF 00`. |
| `FIRMWARE_READY` | Wait for firmware response readiness | Polls STATUS until `01` |
| `FIRMWARE_RESPONSE` | Read and parse firmware response | Reads full response frame, prints IC/Ver/Rev |
| `SAM_WRITE` | `SAMConfiguration` command | Writes frame for command `0x14` |
| `SAM_ACK` | Read ACK for SAM command | Reads 7 bytes. Expects ACK pattern. |
| `SAM_READY` | Wait for SAM response readiness | Polls STATUS until `01` |
| `SAM_RESPONSE` | Read and parse SAM response | Reads response, confirms success |
| `PASSIVE_WRITE` | `InListPassiveTarget` command | Writes frame for command `0x4A` |
| `PASSIVE_ACK` | Read ACK for passive target command | Reads 7 bytes. Expects ACK pattern. |
| `PASSIVE_READY` | Wait for tag-detect response readiness | Polls STATUS until `01` (waits up to `transceive_delay`) |
| `PASSIVE_RESPONSE` | Read tag-detect response | Reads `LEN` bytes. Contains UID if tag found. |

---

## Direct ACK Timing Probe

`FIRMWARE_ACK_DIRECT` writes `GetFirmwareVersion` and immediately reads the ACK frame with a configurable delay between write and read:

```gcode
NFC GATE=0 STEP=FIRMWARE_ACK_DIRECT DELAY=0.050
```

Use this to find the minimum delay that still produces a valid ACK. Start at 50 ms and increase:

```gcode
NFC GATE=0 STEP=FIRMWARE_ACK_DIRECT DELAY=0.100
NFC GATE=0 STEP=FIRMWARE_ACK_DIRECT DELAY=0.200
```

If you find that ACK reads fail below a certain delay, that is a signal about your bus latency (CAN round-trip + PN532 processing). Increase `transceive_delay` to match.

---

## Raw Tools

These bypass the `STEP=` sequence entirely and give direct bus access.

### `READY_READ` — Read the PN532 status byte

```gcode
NFC GATE=0 READY_READ=1
```

Reads 1 byte from the PN532 I2C address.

| Result | Meaning |
|---|---|
| `01` | PN532 is ready — a response is waiting in its buffer |
| `00` | PN532 is busy — still processing the last command |

Use this to check whether the PN532 is alive and whether a previous command completed.

---

### `ACK_READ` — Read the ACK frame

```gcode
NFC GATE=0 ACK_READ=1 LEN=7
```

First reads the STATUS byte. If STATUS is `01` (ready), reads `LEN` more bytes.

**Expected good ACK:**

```
01 00 00 FF 00 FF 00
```

The `01` is STATUS (ready). The remaining 6 bytes are the PN532 ACK frame. If you see anything else, the PN532 is either not ready, or the previous write did not produce a standard ACK.

---

### `RAW_READ` — Read raw bytes

```gcode
NFC GATE=0 RAW_READ=1 LEN=1
```

Reads exactly `LEN` bytes from the PN532 I2C address without any interpretation. The raw bytes are printed to the console.

---

### `RAW_WRITE` — Write raw bytes

```gcode
NFC GATE=0 RAW_WRITE=00
NFC GATE=0 RAW_WRITE=00,00,FF,02,FE,D4,02,2A,00
```

Writes the specified bytes exactly as given. Accepts space, comma, colon, or dash-separated hex values. No framing is added.

---

### `RAW_CMD` — Write a framed PN532 command

```gcode
NFC GATE=0 RAW_CMD=02
```

Builds and sends a complete PN532 command frame for the given command byte. For command `0x02` (`GetFirmwareVersion`) with no additional parameters, the full frame is:

```
00 00 FF 02 FE D4 02 2A 00
```

The driver calculates `LEN`, `LCS`, `TFI`, `DCS` and the preamble/postamble automatically.

---

## Disabling Expert Mode

When bring-up is complete:

```ini
[nfc_gate]
low_level_debug:   False
console_output:    False
```

Restart Klipper.

Normal polling (`READ=1`) will now function without interference from manual bus commands.

---

*Copyright (C) 2026 WoodWorker. Licensed under [GPL-3.0-or-later](https://www.gnu.org/licenses/gpl-3.0.html) — see [LICENSE](../../LICENSE).*

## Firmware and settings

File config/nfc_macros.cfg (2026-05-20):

# =============================================================================
# EMU NFC Gate Reader — Happy Hare Integration Macros
# =============================================================================
# Include this file from printer.cfg alongside the hardware config:
#
#   Per-lane install:
#     [include nfc/nfc_reader.cfg]
#     [include nfc/nfc_macros.cfg]
#     [include nfc/nfc_reader_hw.cfg]
#
#   Shared reader install (single PN532 inside MMU body):
#     [include nfc/nfc_reader.cfg]
#     [include nfc/nfc_macros.cfg]
#     [include nfc/nfc_reader_shared.cfg]
#
#   Hybrid (per-lane + shared reader):
#     [include nfc/nfc_reader.cfg]
#     [include nfc/nfc_macros.cfg]
#     [include nfc/nfc_reader_hw.cfg]
#     [include nfc/nfc_reader_shared.cfg]
#
# Customise the GCode bodies here to match your Happy Hare version.  Do not put
# Happy Hare calls in PN532Driver or SpoolmanClient.
#
# ── Per-lane reader macros ────────────────────────────────────────────────────
# Dispatched by nfc_gates/nfc_gate when a tag is read on a gate reader:
#
#   _NFC_SPOOL_CHANGED : GATE (int)  SPOOL_ID (int)  UID (hex string)  [AUTO_CREATED=1]
#                        [SCAN_FINISH=1] accepted for compatibility
#                        — or when Spoolman is disabled —
#                        GATE (int)  MATERIAL (str, optional)  COLOR (hex str, optional)
#                                    TEMP (int °C, optional)   UID (hex string)
#                                    [SCAN_FINISH=1] accepted for compatibility
#   _NFC_SPOOL_REMOVED : GATE (int)
#   _NFC_TAG_NO_SPOOL  : GATE (int)  UID (hex string)  [SCAN_FINISH=1] accepted for compatibility
#   _NFC_SCAN_UNRESOLVED : GATE (int)
#
# Integration model:
#   NFC_Manager reads the tag UID, asks SpoolmanClient to resolve it to a spool,
#   then dispatches these macros.  Happy Hare's local gate map is the source of
#   truth.  MMU_GATE_MAP updates the local map; MMU_SPOOLMAN SYNC=1 pushes the
#   spool location to Spoolman ("<hostname> @ MMU Gate:<gate>").
#   _NFC_TAG_NO_SPOOL fires when a tag UID is not registered in Spoolman.
#
# ── Shared reader macro ───────────────────────────────────────────────────────
# Wire this into Happy Hare's mmu_macro_vars.cfg:
#
#   variable_user_post_preload_extension: '_NFC_SHARED_PRELOAD'
#
#   _NFC_SHARED_PRELOAD: called by HH's user_post_preload_extension hook after
#     the pregate load.  Validates and commits the staged spool ID.  Safe to
#     leave wired for all loads — it skips while printing and emits an advisory
#     when no spool is pending.
# =============================================================================

[gcode_macro _NFC_SPOOL_CHANGED]
description: Called by nfc_gates/nfc_gate when a spool NFC tag is placed on a gate
gcode:
    {% set gate     = params.GATE | int %}
    {% set uid      = params.UID | default('') %}
    {% if params.SPOOL_ID is defined %}
        {% set spool_id     = params.SPOOL_ID | int %}
        {% set auto_created = params.AUTO_CREATED | default(0) | int %}
        { action_respond_info('<span style="color:lightgreen">[OK]</span> NFC gate %d: spool %d detected (UID %s)%s. Sending to Happy Hare.' % (gate, spool_id, uid, " [new spool]" if auto_created else "")) }
        {% if auto_created %}
        MMU_GATE_MAP GATE={gate} SPOOLID=-1 AVAILABLE=0 QUIET=1
        MMU_GATE_MAP GATE={gate} APPLY=1 QUIET=1
        MMU_SPOOLMAN REFRESH=1 QUIET=1
        {% endif %}
        MMU_GATE_MAP GATE={gate} SPOOLID={spool_id} AVAILABLE=1 SYNC=1 QUIET=1
    {% else %}
        {% set name     = params.NAME     | default('') %}
        {% set material = params.MATERIAL | default('') %}
        {% set color    = params.COLOR    | default('') %}
        {% set temp     = params.TEMP     | default('') %}
        { action_respond_info('<span style="color:lightgreen">[OK]</span> NFC gate %d: tag metadata detected (UID %s) — no Spoolman. name=%s material=%s color=%s temp=%s' % (gate, uid, name, material, color, temp)) }
        MMU_GATE_MAP GATE={gate}{% if name %} NAME={name}{% endif %}{% if material %} MATERIAL={material}{% endif %}{% if color %} COLOR={color}{% endif %}{% if temp %} TEMP={temp | int}{% endif %} AVAILABLE=1 QUIET=1
    {% endif %}
    MMU_GATE_MAP GATE={gate} APPLY=1 QUIET=1
    MMU_SPOOLMAN SYNC=1 QUIET=1


[gcode_macro _NFC_SPOOL_REMOVED]
description: Called by nfc_gates/nfc_gate when a spool NFC tag is removed from a gate
gcode:
    {% set gate = params.GATE | int %}
    {% set mmu_action = printer.mmu.action | default("") | lower %}
    {% if "load" in mmu_action or "unload" in mmu_action or "homing" in mmu_action %}
        { action_respond_info("NFC gate %d: tag absent during MMU operation (%s) — ignoring removal." % (gate, mmu_action)) }
    {% else %}
        { action_respond_info("🧹 NFC gate %d: spool removed. Clearing Happy Hare gate." % gate) }
        MMU_GATE_MAP GATE={gate} SPOOLID=-1 AVAILABLE=0 SYNC=1 QUIET=1
        MMU_GATE_MAP GATE={gate} APPLY=1 QUIET=1
        MMU_SPOOLMAN SYNC=1 QUIET=1
    {% endif %}


[gcode_macro NFC_HH_SYNC_CACHE]
description: Re-seed NFC lane cache from Happy Hare gate map
# Reads the current Happy Hare gate map and tells each NFC lane about its
# current spool assignment.  On the next poll, if the NFC reader sees the same
# spool that HH already knows about, the dispatch is suppressed (no redundant
# MMU_GATE_MAP call).  Call this after a Klipper restart if startup_polling is
# manual, or any time you want to re-align the NFC cache with HH state.
#
gcode:
    {% set num      = printer.mmu.num_gates | int %}
    {% set spool_ids = printer.mmu.gate_spool_id %}
    {% set statuses  = printer.mmu.gate_status %}
    RESPOND PREFIX="NFC" MSG="Syncing NFC cache from Happy Hare gate map ({num} gates)..."
    {% for i in range(num) %}
        {% set spool_id = spool_ids[i] | default(-1) | int %}
        {% set status   = statuses[i]  | default(0)  | int %}
        RESPOND PREFIX="NFC" MSG="  gate {i} → lane{i}  spool_id={spool_id}  status={status}"
        NFC GATE={i} HH_SYNC=1 SPOOL_ID={spool_id}
    {% endfor %}
    RESPOND PREFIX="NFC" MSG="Sync complete. Run NFC GATE=N READ=1 to start polling."


[gcode_macro _NFC_SHARED_PRELOAD]
description: Called by Happy Hare post-preload hook — validates a pending shared-reader spool
# Wire this into Happy Hare's _MMU_SEQUENCE_VARS:
#   variable_user_post_preload_extension: '_NFC_SHARED_PRELOAD'
#
# Override this macro in your own cfg to add pre/post logic around the NFC check.
gcode:
    {% set nfc = printer['nfc_gate shared'] %}
    {% set spool_id = nfc.pending_spool_id | default(-1) | int %}
    {% set has_per_lane_readers = nfc.has_per_lane_readers | default(False) %}
    {% set gate_spool_ids = printer.mmu.gate_spool_id | default([]) | map('int') | list %}
    {% set gate_statuses  = printer.mmu.gate_status   | default([]) | map('int') | list %}
    # A spool is "already assigned" only when it appears in the gate map AND the
    # gate reports filament physically present (gate_status > 0).  A stale entry
    # with status 0 means the spool was ejected without NFC clearing the map
    # (common when the gate has no per-lane reader), so treat it as unassigned.
    {% set ns = namespace(already_assigned=False, assigned_gate=-1) %}
    {% for i in range(gate_spool_ids | length) %}
        {% if gate_spool_ids[i] == spool_id and gate_statuses[i] > 0 %}
            {% set ns.already_assigned = True %}
            {% set ns.assigned_gate = i %}
        {% endif %}
    {% endfor %}
    {% if spool_id > 0 %}
        {% if ns.already_assigned %}
            NFC_SHARED PRELOAD_CHECK=1 EXPECTED_SPOOL_ID={spool_id}
            NFC_SHARED PRELOAD_COMMIT=1 SPOOL_ID={spool_id}
        {% else %}
            NFC_SHARED PRELOAD_CHECK=1 EXPECTED_SPOOL_ID={spool_id}
            NFC_SHARED PRELOAD_COMMIT=1 SPOOL_ID={spool_id}
        {% endif %}
    {% else %}
        {% set target_gate = printer.mmu.gate | default(-1) | int %}
        {% if target_gate >= 0 %}
        MMU_GATE_MAP GATE={target_gate} SPOOLID=-1 NAME=Unknown MATERIAL=Unknown COLOR=FFFFFF55 TEMP=0 AVAILABLE=1 SYNC=1 QUIET=1
        MMU_GATE_MAP GATE={target_gate} APPLY=1 QUIET=1
        {% endif %}
        NFC_SHARED PRELOAD_CHECK=1
    {% endif %}


[gcode_macro _NFC_SHARED_BYPASS_SPOOL_CHANGED]
description: Called by shared NFC reader when Happy Hare bypass is selected
gcode:
    {% set spool_id = params.SPOOL_ID | int %}
    {% set uid      = params.UID | default('') %}
    { action_call_remote_method("spoolman_set_active_spool", spool_id=spool_id) }
    { action_respond_info('<span style="color:lightgreen">[OK]</span> NFC[shared]: bypass active spool set to %d (UID %s)' % (spool_id, uid)) }
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

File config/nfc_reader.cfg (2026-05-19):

# =============================================================================
# EMU NFC Gate Reader — User Settings
# =============================================================================
# Supported documented path:
#   PN532 over I2C on each lane MCU / EBB42 board.
#
# Include order in printer.cfg:
#   [include nfc/nfc_reader.cfg]
#   [include nfc/nfc_macros.cfg]
#   [include nfc/nfc_reader_hw.cfg]
#
# This file defines the base [nfc_gate] section.  Each [nfc_gate laneN]
# section in nfc_reader_hw.cfg inherits these values unless it overrides them.
# =============================================================================

[nfc_gate]

# PN532 default I2C address: decimal 36 == hex 0x24.
i2c_address:         36
i2c_bus:                 i2c2_PB10_PB11          # SLB configuration
#i2c_bus:                 i2c3_PB3_PB4           # EBB42 configuration 

# ── Spoolman ──────────────────────────────────────────────────────────────────
# Use "auto" to read Moonraker's Spoolman configuration, set a direct URL,
# or set "disabled" to skip Spoolman lookup and use tag metadata directly
# when tag_parsing is enabled.
#
#   spoolman_url: auto
#   spoolman_url: http://192.168.1.50:7912
#   spoolman_url: disabled
spoolman_url:        auto

# Spoolman spool extra field that stores the NFC tag UID.
spoolman_rfid_key:   rfid_tag

# HTTP request timeout in seconds.
spoolman_timeout:    5.0

# Seconds to cache a successful UID -> spool lookup.  0 disables cache.
spoolman_cache_ttl:  300

# ── Tag data resolution ──────────────────────────────────────────────────────
# Choose how tags are resolved:
#
#   tag_parsing: False  -> resolve by UID through Spoolman only
#   tag_parsing: True   -> enable rich RFID content reads when supported
#
# Rich read supports NTAG/Type-2 metadata and authenticated Bambu/MIFARE reads.
# Bambu rich reads require pycryptodome in the Klipper Python environment.
tag_parsing:         False

# Allow authenticated Bambu factory-spool reads when tag_parsing is True.
# Leave False unless pycryptodome is installed in the Klipper Python environment.
bambu_reads:         False

# When rich RFID reads produce filament metadata that does not already map to a
# Spoolman spool, allow the plugin to auto-create a new spool record.
spoolman_auto_create: False

# Fallback NTAG user-page window for non-NDEF/binary tags.
# NDEF text/JSON tags are read dynamically from the NDEF TLV length header.
# Default 16 covers the common fixed-size binary formats without extra I2C.
#tag_max_pages: 16

# ── Polling ───────────────────────────────────────────────────────────────────
# Startup polling behavior:
#   -1  manual start only (default, safest)
#    0  explicitly disabled on startup
#    1  start polling automatically after PN532 init succeeds
startup_polling:    1

# Seconds to wait before the first automatic poll when startup_polling=1.
# Override per [nfc_gate laneN] to stagger lane startup and avoid all readers
# entering the first poll cycle at the same time.
startup_poll_delay: 0.0

# Per-lane background poll interval (seconds). Lane readers use this for normal
# tag checks and absent/removal timing. Shared readers do not use this for read
# cadence; they use scan_poll_interval below.
poll_interval:       10

# Consecutive missed polls before a spool is declared removed.
# With poll_interval=30 and absent_threshold=3, removal takes about 90 seconds.
absent_threshold:    3

# ── PN532 timing ──────────────────────────────────────────────────────────────
# Delay around PN532 passive target commands.
transceive_delay:    0.250

# Delay after target release before the next command.
crc_delay:           0.050

# ── Logging ───────────────────────────────────────────────────────────────────
# NFC-specific log file. Relative names resolve under Klipper's log directory.
log_file:            nfc_reader.log

# Log verbosity written to log_file.  Higher number = more output.
#
#   0   — no logging
#   1   — errors only
#   2   — warnings and errors          [recommended for normal use]
#   3   — state changes, Spoolman lookups, HH handoff
#   4   — full I2C protocol trace (verbose — use only when diagnosing)
debug:               2

# Optional Fluidd/Mainsail console output.
# Errors always go to the console once the module has loaded.
# Set console_output: True to also send info/warning messages to the console.
console_output:      False

# Controls which messages appear in the Fluidd/Mainsail console when console_output is True.
# Higher number = more output.  Accepted values:
#
#   1  — errors only
#   2  — warnings and errors          [recommended for normal use]
#   3  — state changes, Spoolman lookups, HH handoff
#   4  — full I2C protocol trace (verbose)
#
# For initial setup / real-time debugging:  console_output: True   console_log_level: 3
# For normal printing:                      console_output: False  console_log_level: 2
console_log_level:   2
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

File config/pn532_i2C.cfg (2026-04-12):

# =============================================================================
# EMU NFC Gate Reader — PN532 I2C Lane Hardware
# =============================================================================
# Supported documented path:
#   one PN532 module per lane MCU / EBB42 board.
#
# Include after nfc_vars.cfg and nfc_macros.cfg:
#   [include NFC/nfc_vars.cfg]
#   [include NFC/nfc_macros.cfg]
#   [include NFC/pn532_i2C.cfg]
#
# Each [nfc_gate laneN] section maps:
#   Happy Hare gate number -> Klipper lane MCU -> PN532 hardware I2C bus.
#
# The lane MCU names must already exist in Klipper / Happy Hare config.
# Example: [mcu lane0], [mcu lane1], etc.
#
# ⚠️ After updating Klipper, rebuild and flash the lane MCU / EBB42 firmware.
# Updating the host alone is not enough for PN532 I2C troubleshooting.
# =============================================================================

# ── Lane 0 ────────────────────────────────────────────────────────────────────
[nfc_gate lane0]
mmu_gate:                0
i2c_mcu:                 lane0
i2c_bus:                 i2c3_PB3_PB4

# ── Lane 1 ────────────────────────────────────────────────────────────────────
[nfc_gate lane1]
mmu_gate:                1
i2c_mcu:                 lane1
i2c_bus:                 i2c3_PB3_PB4

# ── Lane 2 ────────────────────────────────────────────────────────────────────
[nfc_gate lane2]
mmu_gate:                2
i2c_mcu:                 lane2
i2c_bus:                 i2c3_PB3_PB4

# ── Lane 3 ────────────────────────────────────────────────────────────────────
[nfc_gate lane3]
mmu_gate:                3
i2c_mcu:                 lane3
i2c_bus:                 i2c3_PB3_PB4

# ── Lane 4 example ────────────────────────────────────────────────────────────
# [nfc_gate lane4]
# mmu_gate:              4
# i2c_mcu:               lane4
# i2c_bus:               i2c3_PB3_PB4

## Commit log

2026-03-18 updated config file
    [nfc_vars.cfg]
2026-04-10 fixed NFcGateManager with NFCGateManager
    [nfc_gates_i2c_pn532_pico.cfg]
2026-04-10 fixed invented API's wtih real Klipper API's
2026-04-11 deduplicate _lane_instances by lane name on each append
    Klipper can call load_config_prefix more than once per section in a
    single startup cycle. The printer-identity clear only handled the
    cross-restart case. Now replace any existing entry with the same
    lane name instead of blindly appending, so duplicates can't accumulate
    regardless of how many times Klipper visits the section.
2026-04-11 drop default I2C speed from 400kHz to 100kHz for PN532 compatibility
2026-04-11 modified the I2C communications to add the ACK and swallow it
2026-04-11 changed klipper comms
2026-04-12 adding a stand along i2c scanner for a raspberry pi
2026-04-12 full refactoring, and incorporation of the HH base working file. focused on PN532 only
    [nfc_macros.cfg, nfc_vars.cfg, pn532_i2C.cfg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]
2026-04-12 cleaning up repo
    [pn532_pico_i2c.cfg, pn532_spi.cfg, rc522_spi.cfg]
2026-04-13 corrected polling threading issue
2026-04-13 fixing spoolman lookup and a clear cache for the reader
    [nfc_macros.cfg]
2026-04-13 making sure to use happy hare correctly on filament swapping
    [nfc_macros.cfg]
2026-04-15 detailed timing and corner case http/coms optimization
2026-04-20 refreshing documentation, lining up with the code modifications
    [nfc_macros.cfg]
2026-04-20 soldering instructions
2026-04-26 refactoring the scanning and jog. using speed from mmu_config, and fixing the installer
    [nfc_vars.cfg]
2026-04-28 had to move the mmu_select back into the jog loop because the manual jog start was called outside the normal klipper reactor
2026-04-28 resetting baseline config for the scan-jog ootb
    [nfc_vars.cfg]
2026-05-01 implementing the bambu auth, and changing install to a menued item
    [nfc_reader.cfg]
2026-05-02 integrating the lameandboard/rfid work into nfe_reader
    [nfc_macros.cfg, nfc_reader.cfg]
2026-05-02 added back the startup poll delay conf setting.
    [nfc_reader_hw.cfg]
2026-05-03 Python resolves new spool → tag.resolution = {'path': 'auto_create', ...} → dispatch(..., auto_created=True) _run_gcode() adds AUTO_CREATED=1 to the script Macro sees AUTO_CREATED=1 → calls MMU_SPOOL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
2026-05-03 added back the startup delay per lane
    [nfc_reader_hw.cfg]
2026-05-04 quiet spoolman sync
    [nfc_macros.cfg]
2026-05-04 fixing smart quotes and smart punctuation in the openspool reader
    [nfc_macros.cfg]
2026-05-06 updated mount for bambu spools and couple fixes for console notifications
    [LED_holder_NFC_Guard_Bambu_height.stl, LED_holder_with_NFC_Bambu_height.stl]
2026-05-07 updated nfcreader hanger
    [LED_holder_NFC_Guard_Bambu_height.step, LED_holder_NFC_Guard_Bambu_height.stl, LED_holder_with_NFC_Bambu_height.step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]
2026-05-09 Keep HH gate available for unregistered NFC tags
    [nfc_macros.cfg]
2026-05-10 significant changes to implmenet seperate cfg for shared. check share_reader.md in the design docs for update
    [nfc_macros.cfg, nfc_reader_hw.cfg, nfc_reader_shared.cfg]
2026-05-11 dynamic colors on installer, fixed implemented mmu_LED_effect
    [nfc_macros.cfg, nfc_reader_shared.cfg]
2026-05-12 mplemented shared-reader LED feedback states:
    Added yellow 2x tag-detected acknowledgement via shared_tag_read_effect
    Added green 2x spool-ready acknowledgement via new shared_spool_ready_effect
    Added red 5x unresolved-UID feedback via new shared_tag_unresolved_effect
    Changed auto-create feedback to a yellow chase using the EMU mmu_clockwise_fast chase pattern
    Started/stopped the auto-create LED effect around Spoolman spool creation
    Updated shared config template, installer output, docs, and tests
    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
    [nfc_macros.cfg, nfc_reader_shared.cfg]
2026-05-13 debugging the shared reader
    [nfc_macros.cfg]
2026-05-13 removed emoji and shortened default dwell between micro steps
    [nfc_macros.cfg, nfc_reader.cfg]
2026-05-14 Added UID-based left-neighbor detection in scan_jog.py (line 285).
    Added one-time 75 mm left-neighbor clearance and restore-on-exit behavior in scan_jog.py (line 435).
    Added lane lookup support and scan state fields in nfc_manager.py (line 122).
    Added focused scan-jog tests for gate 0, UID match/no-match, stale HH cache veto, restore paths, and repeated-hit abort behavior in test_scan_jog_mode.py (line 1305).
    Updated README and design/user docs to describe the implemented behavior.
    fixed test stub in test_gate_state.py so the full suite runs cleanly in one process.
2026-05-14 cleaning up messaging in the console
    [nfc_macros.cfg]
2026-05-14 changed scan_jog to return a UID found but spoolman unresolved, and a no UID found as separate exit paths
    [nfc_macros.cfg]
2026-05-14 added a 3 attempt jog for the left lane, clearing interfernence reads. if after 3 reads the interference is not cleared, the scan jog will error out. Left spool will be reparked at Load position afte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
    [nfc_macros.cfg]
2026-05-15 making sure rewind is noted when there is no UID read. rewind should be noted in the console as a notification
    [nfc_macros.cfg]
2026-05-16 Add spool-level identity metadata for structured tags
    Bambu factory spools can carry two physical NFC tags, one on each side of the spool. Those tags have different physical UIDs, but they describe the same spool and share the Bambu tray_uid stored in the authenticated MIFARE data.
    The left-neighbor interference work needs a way to compare the spool identity rather than only comparing the physical tag UID. A UID-only comparison cannot detect the case where lane 1 reads the opposite-side tag of the already-loaded lane 0 Bambu spool, because that opposite tag is expected to have a different UID.
    Introduce CurrentTag.spool_identity as an optional normalized spool-level identity copied from pa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
2026-05-16 Use spool identity for left-neighbor interference
    The previous left-neighbor mitigation compared the current read UID with the cached UID from gate N-1. That is not reliable for the PN532/Bambu interference case we observed: a Bambu spool can have one physical tag on each side, the two tags have different NFC UIDs, and the adjacent reader is expected to see the near-side tag rather than the far-side tag cached by the left gate.
    Switch the positive interference proof to parser-supplied spool_identity. Scan-jog now treats a read as left-neighbor interference only when the current tag has a spool_identity, the immediate left gate has a cached current_tag.spool_identity, and the two identities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
2026-05-19 Sync from private repo
    [nfc_macros.cfg]
